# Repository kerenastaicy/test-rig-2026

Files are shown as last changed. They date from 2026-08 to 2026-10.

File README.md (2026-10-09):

# test-rig-2026
# INTELLIGENT SORTING SYSTEM

## PROJECT OVERVIEW

The Intelligent Sorting System is an automated conveyor-based sorting mechanism designed to identify and sort objects into designated bins based on their type. The system uses computer vision for object classification and an ESP32 microcontroller for coordinating conveyor movement, sensor input, and servo-controlled sorting.

The system begins with objects placed on the conveyor belt manually. There is no feeder mechanism. Objects are transported to a designated inspection area, where a camera captures images for classification using a Python-based computer vision program. The system classifies each object as a nut, bolt, or miscellaneous object.

Once the classification is complete, the ESP32 controls the conveyor to transport the object towards the sorting end. An IR sensor detects the object's arrival, allowing the controller to stop the conveyor and actuate an MG995B servo motor attached to a movable chute. The chute rotates to the appropriate angle, directing the object into its designated bin through gravity.

The system follows a sequential control process to coordinate object identification, transportation, and sorting while minimizing the possibility of misclassification or mixing consecutive objects.

## SYSTEM ARCHITECTURE

The project consists of the following subsystems:

- Conveyor Mechanism: Transports objects from the inspection area to the sorting end using a NEMA 17 stepper motor.
- Computer Vision: Uses Python and OpenCV to process camera images and classify objects as nuts, bolts, or miscellaneous items.
- Microcontroller: An ESP32 coordinates the conveyor motor, IR sensor, and servo actuator, while communicating with the computer vision program.
- Motor Driver: A DRV8825 drives the NEMA 17 stepper motor responsible for conveyor movement.
- Object Detection Sensor: An IR sensor positioned at the end of the conveyor detects an arriving object and signals the controller.
- Servo-Actuated Sorting Chute: An MG995B servo rotates a gravity-fed chute to direct objects into the appropriate collection bin.
- Power Supply: A 12 V SMPS supplies the motor driver, while a buck converter provides an appropriate regulated supply for the servo.

## WORKING PRINCIPLE
1. Object Placement: An object is placed manually on the conveyor belt.
2. Inspection: The conveyor transports the object to the inspection area, where movement can be paused for image capture and classification.
3. Classification: The computer vision program identifies the object as a nut, bolt, or miscellaneous item.
4. Communication: The classification result is transmitted from the computer to the ESP32.
5. Transportation: The ESP32 resumes conveyor movement, carrying the classified object towards the sorting end.
6. Arrival Detection: The IR sensor detects the object's arrival near the chute and signals the ESP32 to stop the conveyor
7. Sorting: Based on the stored classification, the ESP32 positions the servo-actuated chute at the corresponding angle, allowing the object to fall into the designated bin.
8. Reset: The chute returns to its home position, and the system prepares for the next object.

## TECHNOLOGY AND COMPONENTS
- Programming: Python, C++ (Arduino framework)
- Computer Vision: OpenCV
- Microcontroller: ESP32 DevKit
- Conveyor Drive: NEMA 17 stepper motor and DRV8825 driver
- Sorting Actuator: MG995B servo motor
- Sensing: IR obstacle detection sensor
- Communication: USB serial between the computer and ESP32, with Wi-Fi communication as a potential extension
- Mechanical Design: CAD-designed conveyor structure and servo-mounted gravity chute

## FUTURE IMPROVEMENTS
- Improve classification robustness under varying lighting and background conditions.
- Add more object categories and collection bins.
- Implement wireless communication between the computer and ESP32.
- Improve system throughput and handling of consecutive objects.
- Add sorting statistics, event logging, and performance evaluation.

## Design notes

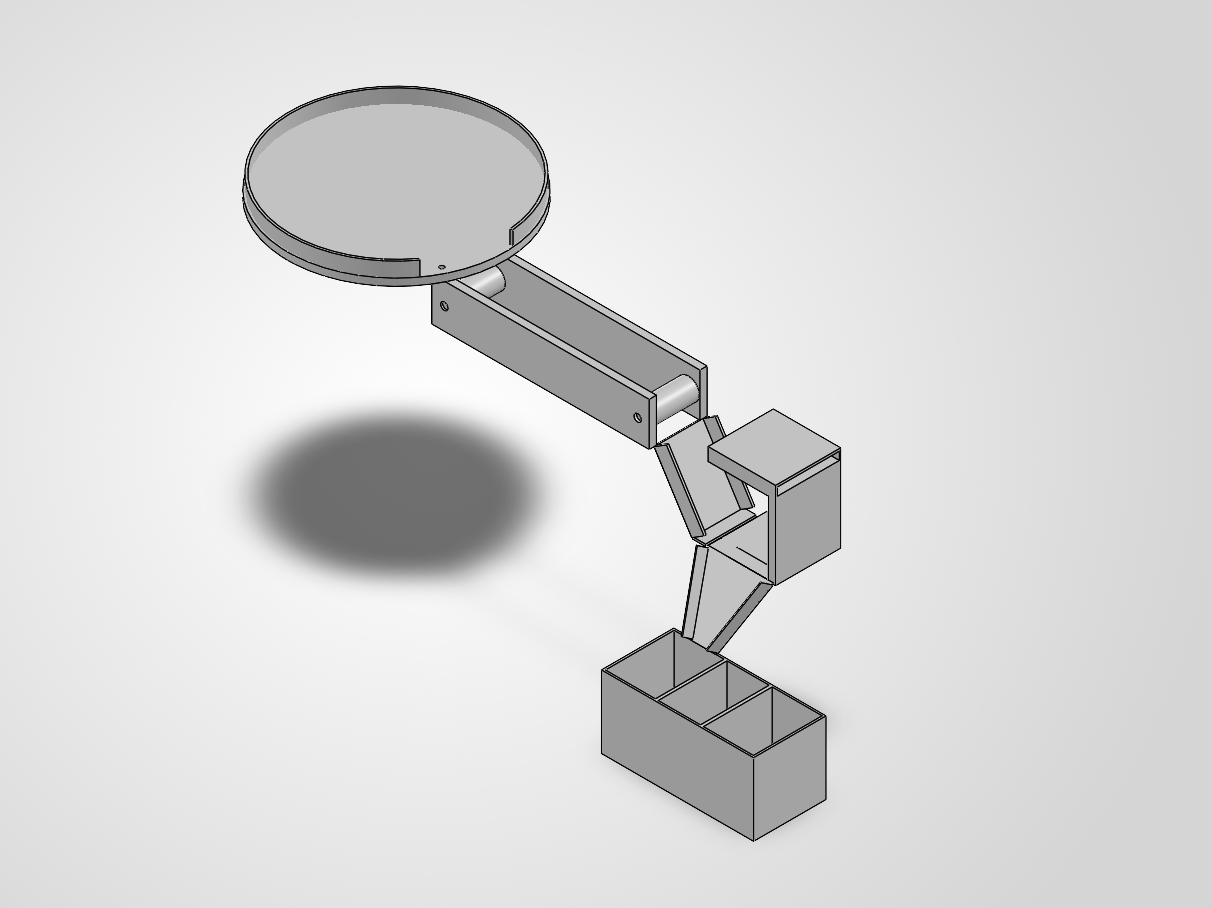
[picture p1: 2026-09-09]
cad/model_2/Screenshot 2026-09-09 174657.png

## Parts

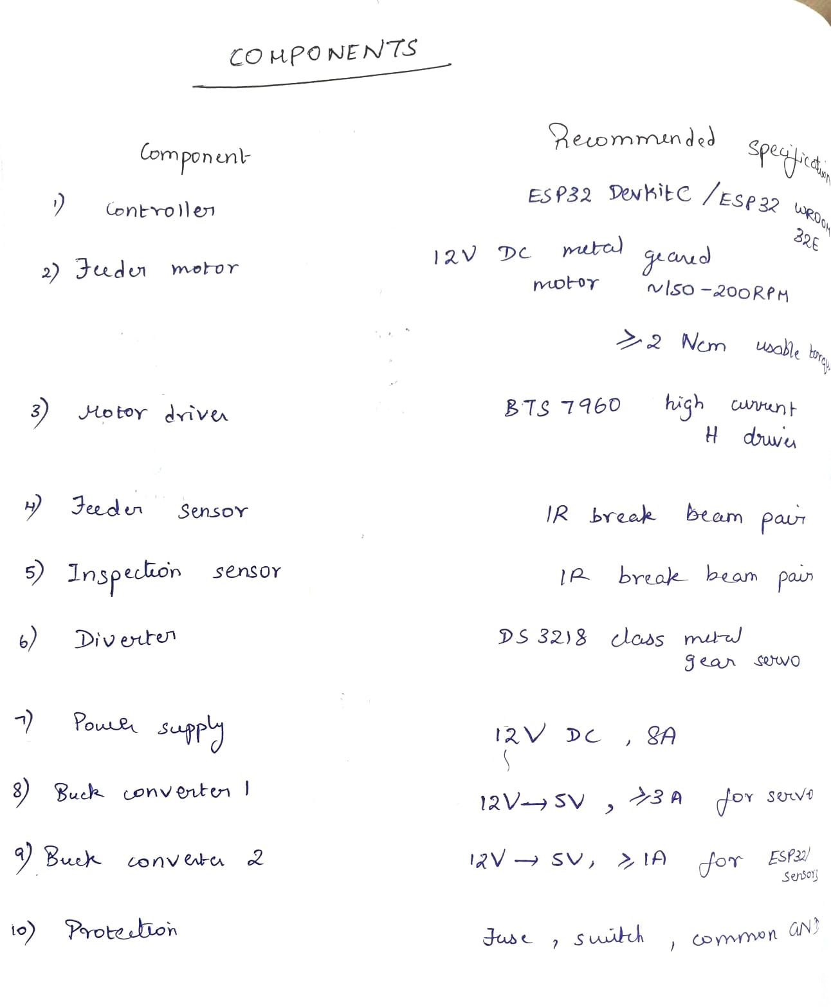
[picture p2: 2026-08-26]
docs/Components.jpeg

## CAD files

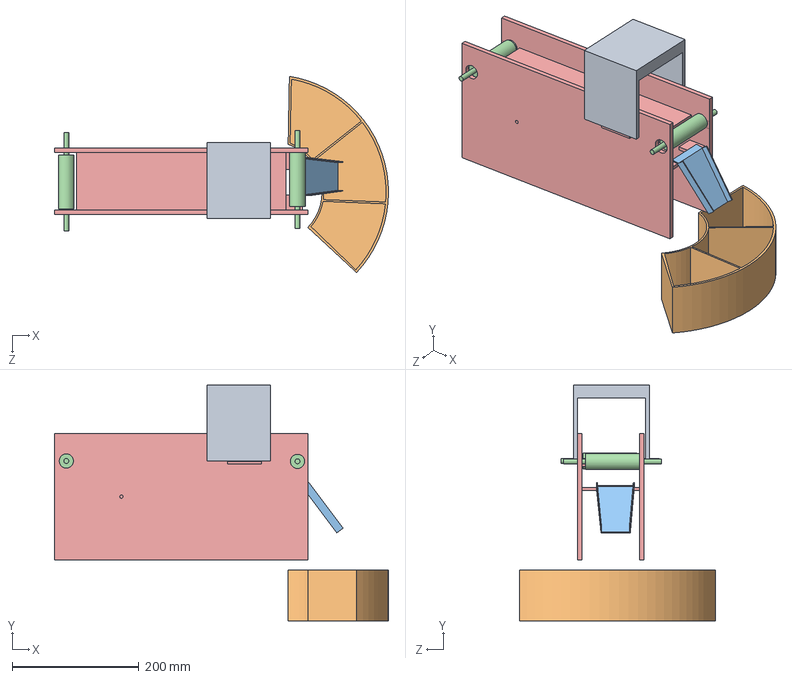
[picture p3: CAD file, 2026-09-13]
cad/model_3/completed_Assembly.SLDASM
526.8 x 371.9 x 309.6 mm
conveyor
conveyor shaft x 2
actuator_new
collection_box
phone mount

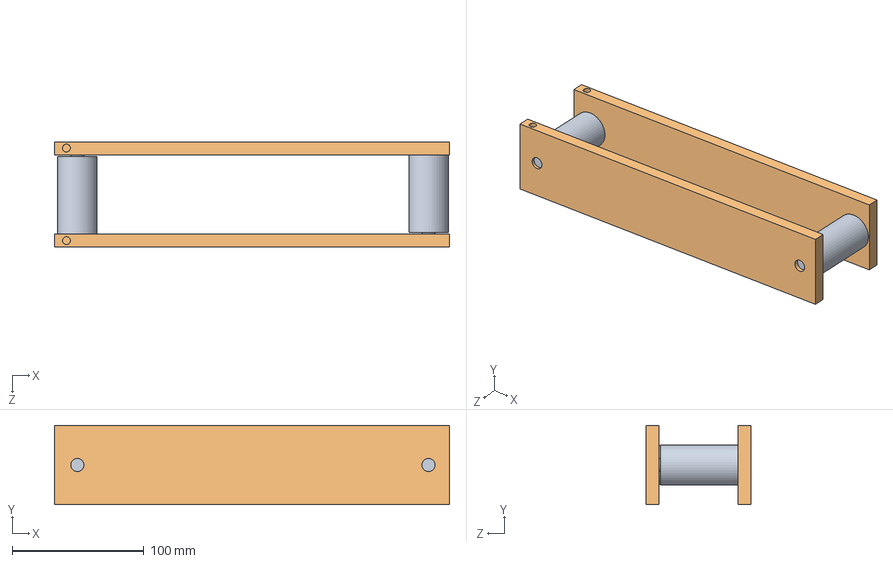
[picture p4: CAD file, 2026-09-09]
cad/model_2/conveyor_assembly.SLDASM
300.0 x 60.0 x 80.0 mm
conveyor_support
conveyor_shaft x 2

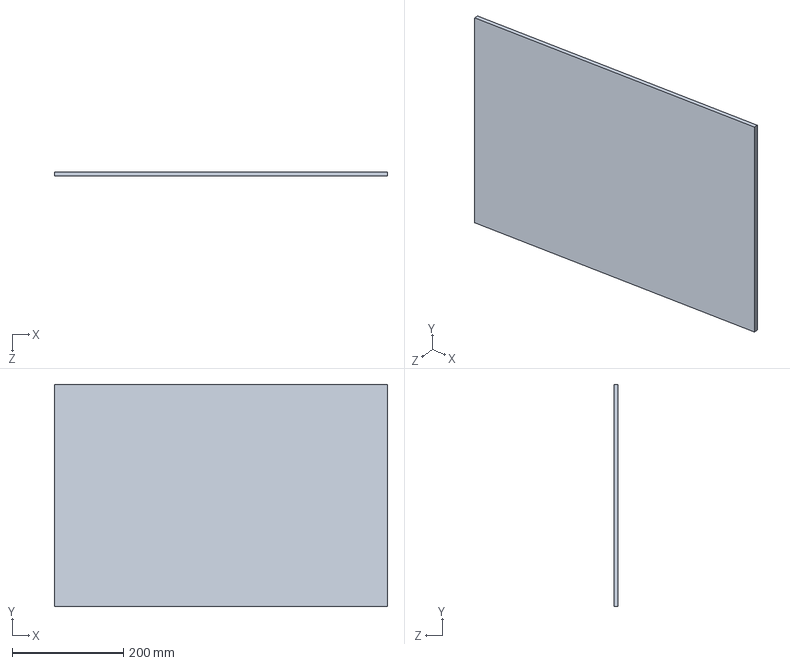
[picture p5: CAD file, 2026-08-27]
cad/base.SLDPRT
600.0 x 400.0 x 8.00 mm

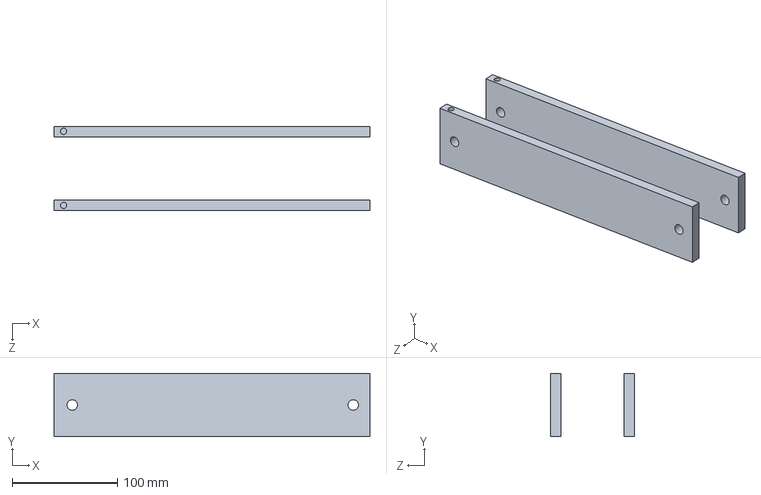
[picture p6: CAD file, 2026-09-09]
cad/model_2/conveyor_support.SLDPRT
300.0 x 60.0 x 80.0 mm

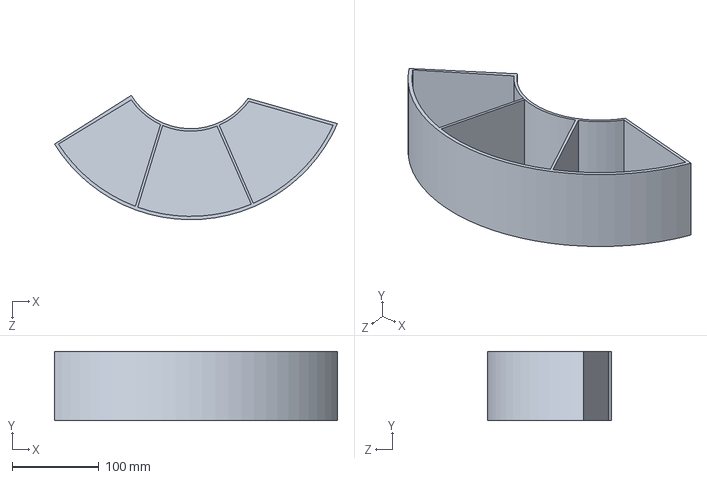
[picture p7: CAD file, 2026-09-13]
cad/model_3/collection_box.SLDPRT
326.3 x 80.0 x 143.4 mm

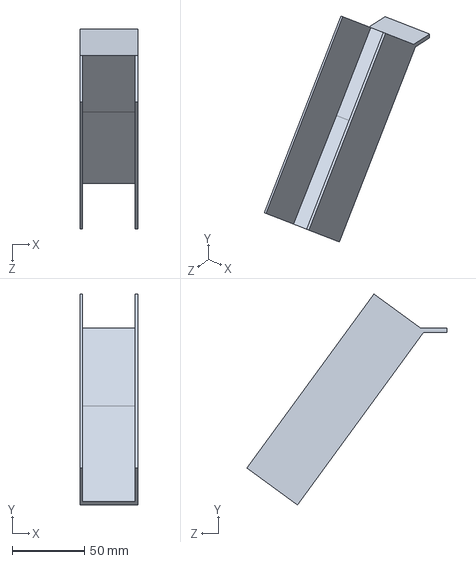
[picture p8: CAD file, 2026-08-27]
cad/gravity_chute.SLDPRT
40.0 x 146.1 x 138.7 mm

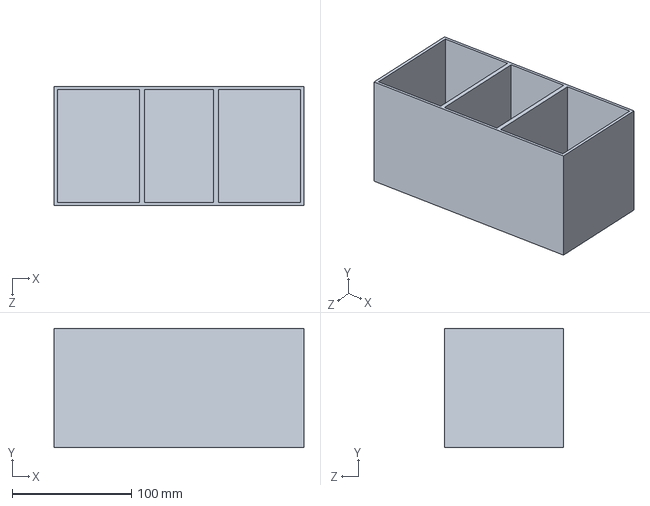
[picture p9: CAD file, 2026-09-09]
cad/model_2/boxes.SLDPRT
210.0 x 100.0 x 100.0 mm

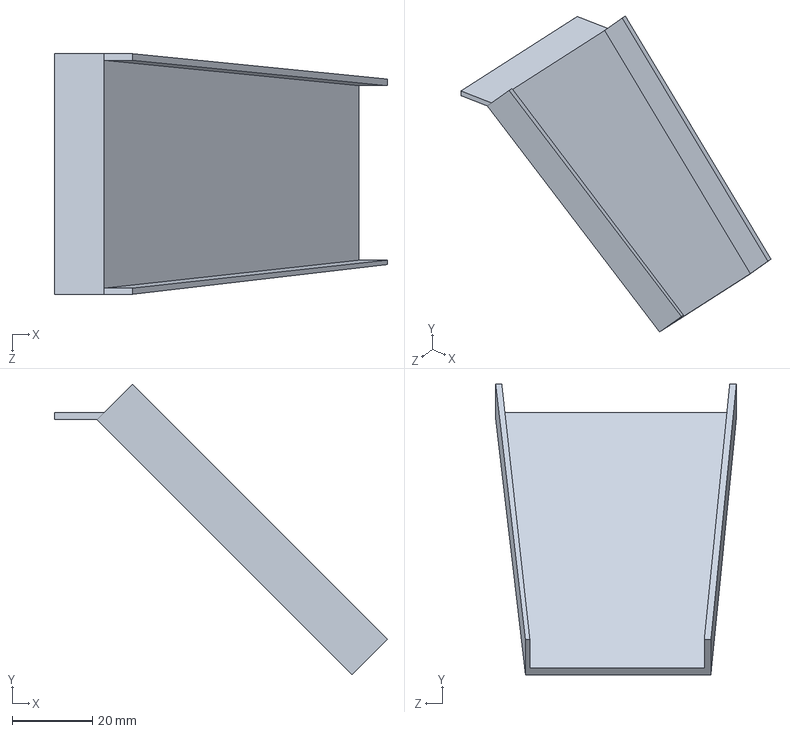
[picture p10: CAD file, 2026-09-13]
cad/model_3/actuator_new.SLDPRT
83.0 x 72.4 x 60.0 mm

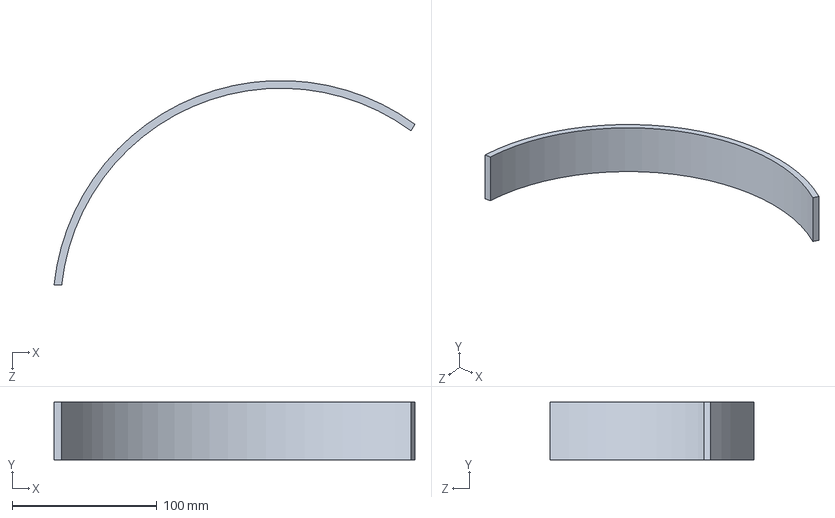
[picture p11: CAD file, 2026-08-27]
cad/curved_guide.SLDPRT
249.0 x 40.0 x 141.0 mm

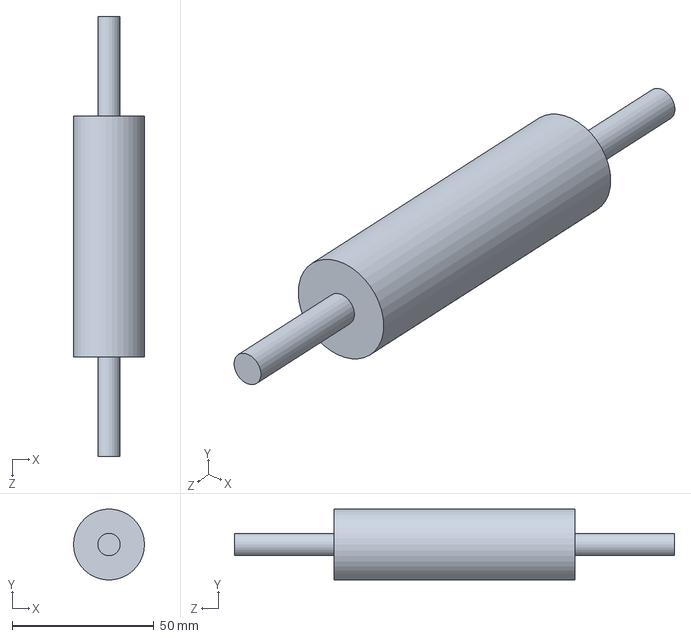
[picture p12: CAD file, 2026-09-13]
cad/model_3/conveyor shaft.SLDPRT
25.0 x 24.9 x 155.0 mm

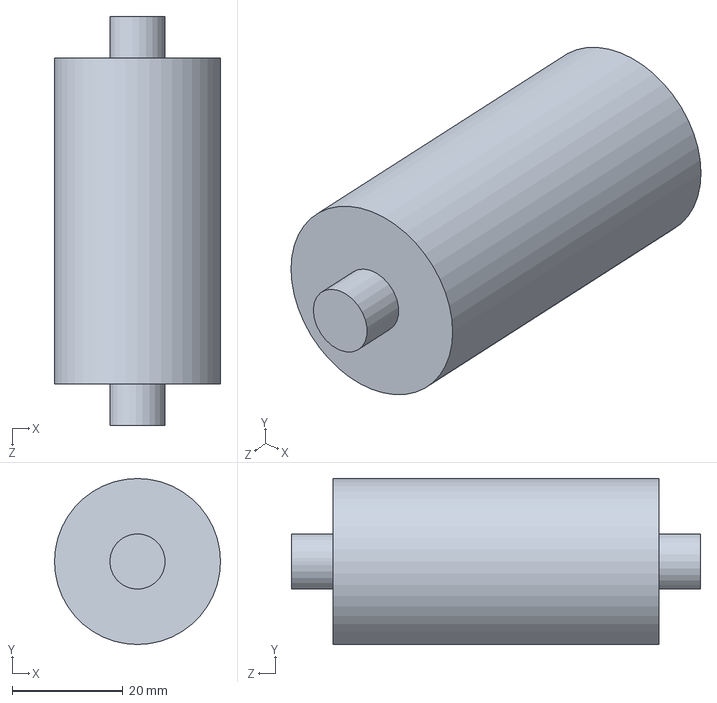
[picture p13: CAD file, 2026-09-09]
cad/model_2/conveyor_shaft.SLDPRT
30.0 x 30.0 x 74.0 mm

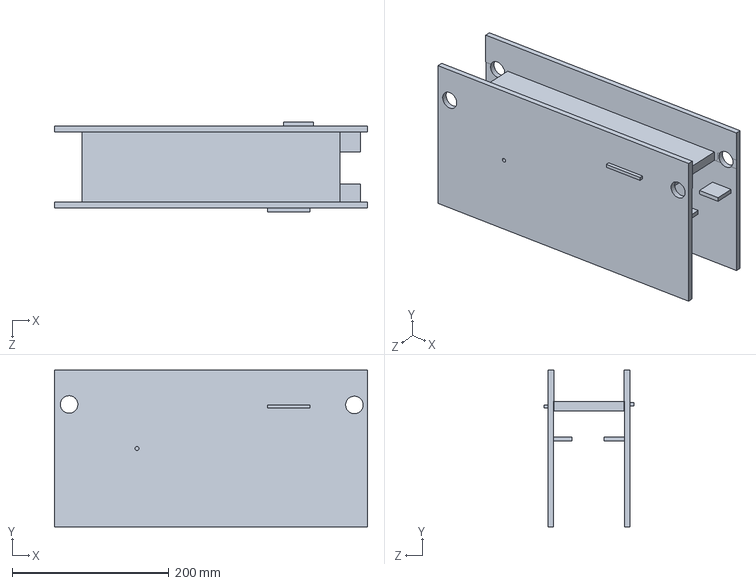
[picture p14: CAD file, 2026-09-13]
cad/model_3/conveyor.SLDPRT
400.0 x 200.0 x 115.0 mm

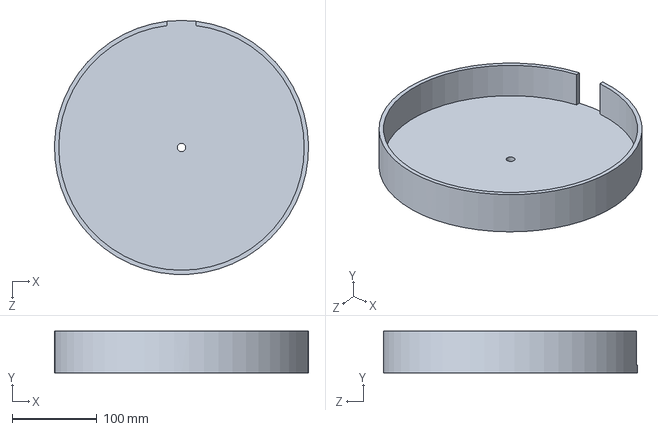
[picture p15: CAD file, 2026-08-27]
cad/rotating_disc.SLDPRT
299.9 x 49.0 x 300.0 mm

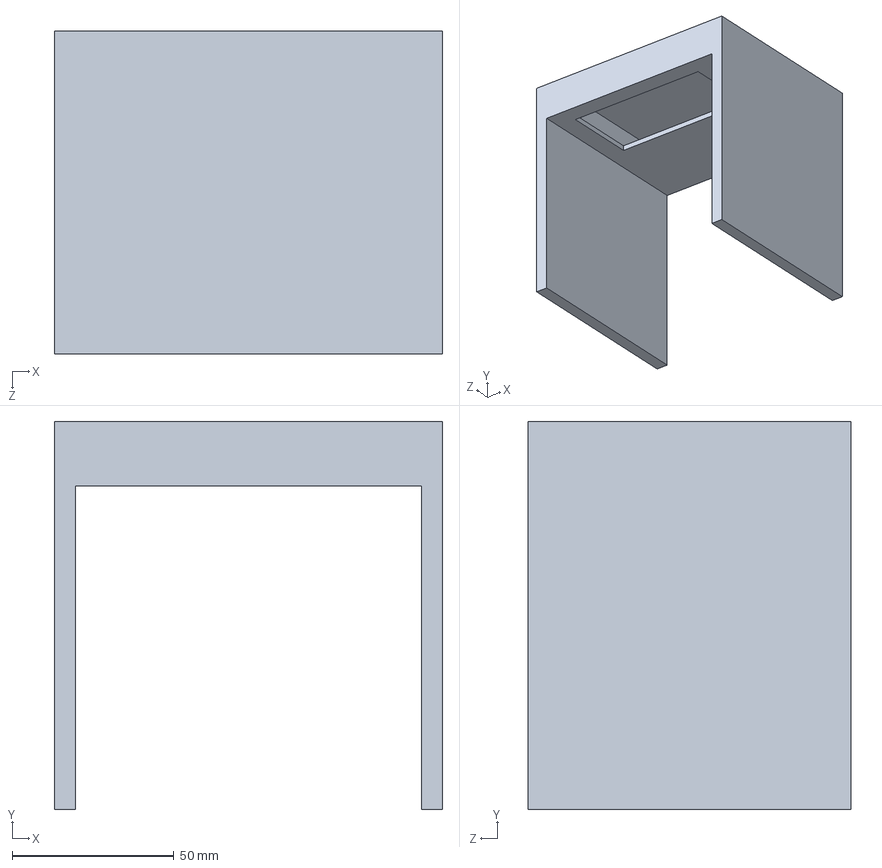
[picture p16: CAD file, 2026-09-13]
cad/model_3/phone mount.SLDPRT
120.0 x 120.0 x 100.0 mm

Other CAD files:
cad/model_2/rotator_assembly.SLDASM
cad/model_2/rotator assembly _ne.SLDASM
cad/model_2/complete_assembly.SLDASM
cad/model_2/Assem1.SLDASM
cad/model_2/actuator.SLDPRT
cad/model_2/gravity_chute.SLDPRT
cad/model_2/inspection_area.SLDPRT
cad/model_2/rotator_base.SLDPRT
cad/model_2/wall_rotator.SLDPRT

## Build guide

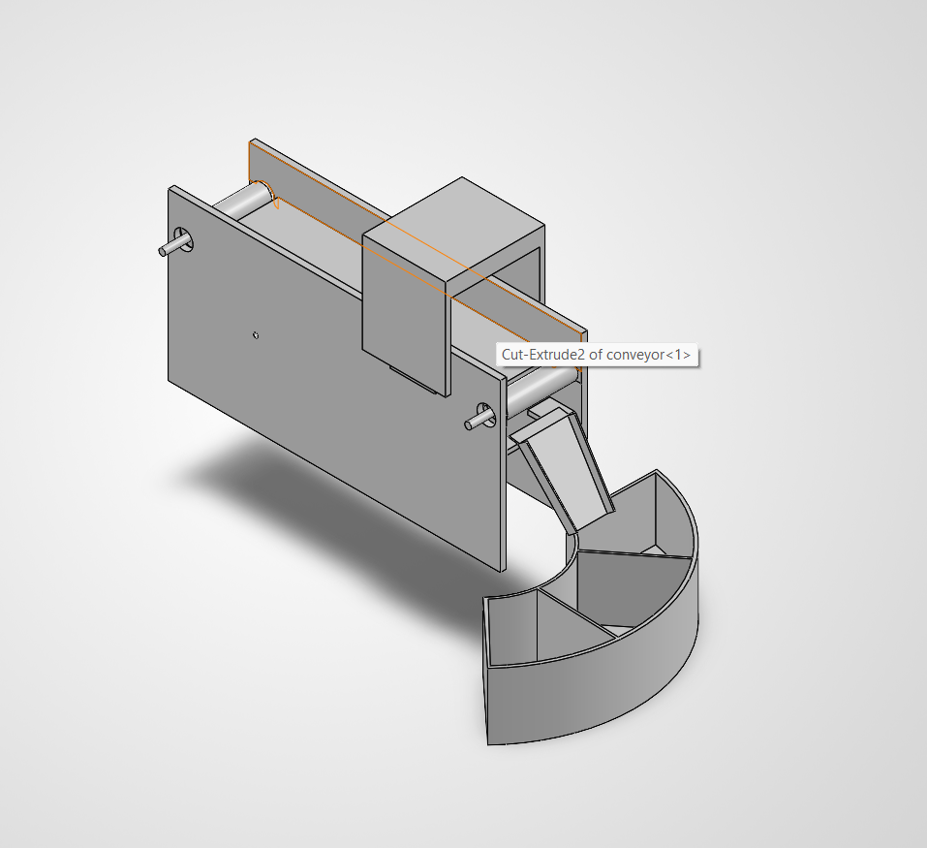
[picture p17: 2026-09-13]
cad/model_3/assembly_screenshot.png

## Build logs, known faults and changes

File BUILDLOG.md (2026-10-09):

## 13 August 2026
- Created the GitHub repository.
- Set up the initial folder structure.
## 18 August 2026
- Understood the overall architecture and working of system
- Decided feeding mechanism: **rotational disc feeder + curved singulation guide + gravity chute**

 A rotating disc feeder with a curved singulation guide and gravity chute was selected for the initial prototype. The rotating disc provides controlled movement of the mixed objects, while the curved guide encourages single-item flow without requiring a tightly constrained escapement mechanism. Gravity is used for transport after singulation, eliminating the need for an additional conveyor motor.

- Made overall list of components needed ( did not check specifications yet)
  
## 19 August 2026
### Sorting mechanism
#### initial idea: 
-vertical stack (item free-falls straight down a shaft; each level has a trapdoor — closed by default drops it there, open lets it fall further)
- Would need 2 servos and a more coordination needed
#### better idea
- Rotating diverter: The item drops onto the trough, gravity slides it down the trough's slope, and it lands wherever the trough is currently pointed.

### JAM RECOVERY IDEA
-IR Break beam sensing: can fit an IR sensors near the feeder output  . If the IR beam is not broken for a long time , then the object is jammed in the feeder.
-Now the disc rotates in the opposite direction to recover from the jam.

### WHAT I DID?
- Finalised the overall working mechanism of the system
- Completed necessary block diagrams of circuit and connections.
- Analysed the required voltage/ current by each component
- Made detailed component list 
- Waiting for confirmation of the availability of components

  ### CHALLENGE
  - What if the items enter inspection area quicker than the sorting function, then multiple items will enter inspection area.
 
## 20 August 2026

### WHAT I DID?
- ML CV part: YOLOv8n object detection with three classes: Nut, Bolt, and Misc.
  #### WHY?
  - Multiple objects: YOLO can detect that 2+ objects arrived, whereas classical CV would need more hand-written rules.
  - Orientation: More robust when nuts/bolts are rotated
  - Lighting: Generally more robust to changes in lighting and appearance.
  - Misc: You can use a confidence threshold; low-confidence detections go to Misc.
  - Future-proof: If you later add more object types, you can retrain the model.
  -  - Analysed the communication and interfaces

## 22 August 2026
- Started CAD modelling of major parts with approximate dimensions
 
  ## 26 August 2026
 Analysed the drawback and complexity of binary cascade flap ( synchronizing of the flap opening timing)
 ### found out a better sorting mechanism: actuated chute
- updated the architecture

  ## 8 September 2026
  - Realised that adding conveyor would make the model more efficient
  - Designed and assembled overall CAD. Further improvements to be made
## 13 September 2026
- Finalised the CAD model with new updates.

## 25 September 2026
 - Built basic structure of conveyor

## 29 September 2026
- did the wirings

## 4 October 2026
- Modified the overall structure of the conveyor to make it more stable
- 3d printed stepper mount
- tried to make stepper work using 5v smps and l293d driver

## 9 October 2026
CHALLENGES: 
- stepper only vibrating
- servo not moving when connected using buck converter and 12v smps
- CV capturing random light reflections as items

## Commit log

2026-08-13 Add initial CAD files README
2026-08-18 Add details about feeding mechanism
    Documented the understanding of system architecture and selected feeding mechanism for the prototype.
2026-09-09 Update BUILDLOG with new design entries
    Added new entries for updates on 8 September 2026 regarding conveyor efficiency and CAD design.
2026-09-13 Add entry for CAD model updates on 13 September 2026
2026-09-26 Add entry for conveyor structure in BUILDLOG
